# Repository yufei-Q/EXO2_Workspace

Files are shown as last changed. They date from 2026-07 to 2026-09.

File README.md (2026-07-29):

# EXO2 Workspace

本仓库统一管理外骨骼控制系统的 STM32 固件、ROS 1 Noetic 上位机和 ROS 2 Jazzy 上位机代码。所有电脑都使用同一个 `main` 分支并下载完整仓库。

## 目录结构

```text
EXO2_Workspace/
├── stm32/
│   ├── EXO2_DM_G474/       STM32G474 七电机正式工程
│   ├── EXO2_DM_MOTOR/      STM32F407 旧版四电机工程
│   └── motor_test/         STM32F407 电机测试工程
├── ubuntu/
│   ├── ros_noetic/         Ubuntu 20.04 + ROS 1 Noetic
│   └── ros_jazzy/          Ubuntu 24.04 + ROS 2 Jazzy
├── windows/                Windows USB CDC上位机工具
└── docs/
    └── archive/            历史测试说明
```

当前正式配套代码：

- STM32：[stm32/EXO2_DM_G474](stm32/EXO2_DM_G474)
- ROS 1：[ubuntu/ros_noetic/exo_bringup](ubuntu/ros_noetic/exo_bringup)
- ROS 2：[ubuntu/ros_jazzy/exo_bringup](ubuntu/ros_jazzy/exo_bringup)
- 通信协议：[stm32/EXO2_DM_G474/G474_MOTOR_PROTOCOL.md](stm32/EXO2_DM_G474/G474_MOTOR_PROTOCOL.md)

三套正式代码均对应7台电机：CAN ID 1～4为D4340P，CAN ID 5～7为D4310P；USB控制帧156字节，反馈帧114字节。7台电机共享一个全局控制模式，支持MIT模式和速度模式。

## 分支规则

仓库只长期维护 `main`。Windows、Ubuntu 20.04和Ubuntu 24.04电脑都直接在 `main` 上工作。

每次开始修改前：

```bash
git switch main
git pull --rebase origin main
```

修改和测试完成后：

```bash
git status
git diff
git add -A
git status
git commit -m '说明本次修改'
git push origin main
```

提交前必须检查 `git status`。不要提交Keil、catkin、colcon和Python生成文件。

更完整的协作规则见 [docs/REPOSITORY_WORKFLOW.md](docs/REPOSITORY_WORKFLOW.md)。

## STM32工程

正式工程文件：

```text
stm32/EXO2_DM_G474/EXO2_DM_G474.ioc
stm32/EXO2_DM_G474/MDK-ARM/EXO2_DM_G474.uvprojx
```

Keil编译输出不会进入Git。其他电脑第一次编译时，Keil会重新生成输出目录和HEX文件。

## ROS文档

- ROS 1安装和运行：[ubuntu/ros_noetic/exo_bringup/README.md](ubuntu/ros_noetic/exo_bringup/README.md)
- ROS 2安装和运行：[ubuntu/ros_jazzy/exo_bringup/README.md](ubuntu/ros_jazzy/exo_bringup/README.md)

ROS 1和ROS 2是两套独立代码，功能包名称统一为 `exo_bringup`，节点接口和USB协议保持一致；不要在两个目录之间复制构建产物。

Windows独立测试工具见 [windows/stm32_usb_motor_tool](windows/stm32_usb_motor_tool)。

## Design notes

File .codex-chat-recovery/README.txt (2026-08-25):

Codex local chat recovery backup

Created: 2026-08-12 11:30:53 Asia/Shanghai

Reason:
Older STM32 chat sessions were associated with E:\ZJU\stm32_project,
which no longer exists. The active workspace is now:
E:\ZJU\EXO\stm32\stm32_project

Backup files in the timestamped directory were created before changing
the old sessions' cwd association in the Codex state database.

No authentication files are included.

The timestamped backup directory is intentionally ignored by Git because
it contains private local conversation metadata.

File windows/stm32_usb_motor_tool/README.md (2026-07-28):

# Windows STM32 USB 电机测试工具

该工具通过 Windows 的 USB CDC 虚拟串口直接与 `EXO2_DM_G474` 通讯，不依赖 ROS。协议与 STM32 当前的 7 电机 USB 协议一致：控制帧 156 字节，反馈帧 114 字节，默认控制和反馈频率为 500 Hz。

## 安装

安装 Python 3，然后在 PowerShell 中进入本目录：

```powershell
py -m pip install -r requirements.txt
```

列出串口：

```powershell
py .\stm32_motor_console.py --list
```

启动程序（把 `COM3` 换成实际端口）：

```powershell
py .\stm32_motor_console.py --port COM3 --rate 500
```

串口的 `115200` 仅用于满足虚拟串口接口参数；USB CDC 的实际传输不由传统 UART 波特率决定。

## 安全测试顺序

开始前确保 ROS 节点、串口助手等程序已经关闭，同一时刻只能有一个程序打开该 COM 口。首次测试只连接1号电机，并确保可以随时切断48 V电源。

程序启动后默认持续发送“全部失能、全部目标为零”的安全帧。

先检查 STM32 USB feedback：

```text
motor> stats
motor> feedback
```

`RX` 应持续增加。电机未使能时，反馈值可能为零或保持上一次数据。

只使能1号电机，控制量仍保持全零：

```text
motor> enable 1
```

设置1号电机MIT目标，参数依次为位置、速度、Kp、Kd、前馈力矩：

```text
motor> set 1 0 0 0 0 0
```

建议先保持 `Kp=0`、`Kd=0`、`torque=0`，确认反馈正常后再从很小的增益和目标开始。

读取最新反馈：

```text
motor> feedback
```

失能1号电机：

```text
motor> disable 1
```

其他命令：

```text
clear 1       清除1号电机错误
zero 1        将1号电机当前位置设为零位
enable all    使能全部电机（首次测试不要使用）
disable all   失能全部电机
stats         查看USB收发及CRC计数
quit          失能全部电机并退出
```

退出程序时会连续发送5帧全部失能指令，然后关闭串口。

## 判断结果

- `TX` 增加、`RX` 增加：Windows 与 STM32 USB 双向通讯正常。
- `TX` 增加、`RX=0`：STM32 没有向电脑返回数据，或打开了错误的 COM 口。
- `CRC errors` 增加：上下位机协议或数据流存在不一致。
- feedback 持续收到但电机字段不变化：USB 正常，应检查 STM32 与电机的 FDCAN 接收。

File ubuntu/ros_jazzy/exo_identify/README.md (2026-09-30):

# exo_identify

七自由度外骨骼的 MuJoCo 动力学数据采集、Pinocchio 线性参数辨识、独立验证，以及
ROS 2 实机采集/重力补偿工具。默认模型是：

```text
urdf/exo.SLDASM/urdf/装配体.SLDASM.urdf
```

该模型包含 `joint1` 到 `joint7`、完整惯量和 SolidWorks STL 网格。旧的
`urdf/estimator_kinematics.urdf` 仅保留作历史参考，不再是默认辨识模型。

`urdf/exo.SLDASM/` 保留 SolidWorks 导出的完整 URDF 文件夹，包括网格、关节名
配置及原始 ROS 1 导出元数据。当前 ROS 2 程序直接读取其中的
`urdf/装配体.SLDASM.urdf` 和 `meshes/`；其余导出文件作为模型来源和兼容参考保留，
不会被当前 ROS 2 主流程主动调用。

### 单独检查 MuJoCo 模型方向

在确定安装坐标系前，仅使用 `scripts/mujoco_model.py` 检查模型，不运行数据采集
或辨识。该脚本的姿态、关节、重力和自由体选项只作用于本次生成的 MuJoCo 模型，
不会修改 URDF 或辨识配置。

直接运行脚本会读取统一配置、生成预览 MJCF，并打开交互式 MuJoCo Viewer。省略
`--base-rpy` 和 `--base-pos` 时，程序读取 `config/identification.json` 中
`simulation.base_orientation_rpy` 和 `simulation.base_position`：

```bash
cd ~/exo_ws/src/exo_identify
python3 scripts/mujoco_model.py
```

该命令还会打开关节角度控制面板。七个滑块使用角度制，右侧实时显示实际角度和
执行器力矩。`Angle control (actuators)` 默认关闭，此时电机力矩为零，各关节在
重力下自由运动；开启后使用配置文件中的 `position_kp`、`velocity_kd` 和
`torque_limits` 进行重力前馈加 PD 角度控制。`Hold current pose` 会把当前实际角度
设为目标并开启控制，`Reset` 恢复 `--joint-positions` 指定的初始姿态。MuJoCo Viewer
中的快捷键 `C`、`H`、`R` 分别对应切换控制、保持当前姿态和复位。

寻找机械角度限幅时，可慢速移动单个关节滑块，并观察实际角度、力矩和接触数量。
滑块默认范围为 `-180` 到 `180` 度，可按需要修改；例如：

```bash
python3 scripts/mujoco_model.py --angle-range-deg -120 120
```

若希望启动时立即保持初始设定角度，加入 `--control-on`。只需要原始 Viewer、不需要
角度控制面板时使用 `--no-gui`。

无图形桌面或只想做无窗口检查时使用 `--no-viewer`；需要保存 PNG 时才显式加入
`--preview`，默认写入 `results/seven_dof/model_visualization/exo_orientation.png`：

```bash
python3 scripts/mujoco_model.py \
  --joint-positions 0 0 0 0 0 0 0 \
  --show-frames --fixed-base --no-viewer --preview
```

测试候选方向时，可以直接用弧度覆盖配置，例如绕世界 Y 轴旋转 90 度：

```bash
python3 scripts/mujoco_model.py \
  --base-pos 0 0 0 \
  --base-rpy 0 1.5708 0 \
  --joint-positions 0 0 0 0 0 0 0 \
  --show-frames --fixed-base --no-viewer \
  --preview results/seven_dof/model_visualization/exo_orientation_y90.png
```

有图形桌面时也可以显式写 `--viewer` 查看交互窗口；两者不能同时使用：

```bash
python3 scripts/mujoco_model.py --show-frames --fixed-base --viewer
```

`--base-rpy` 使用弧度，顺序为世界坐标中的 XYZ roll/pitch/yaw；`--gravity`
是 MuJoCo 世界坐标中的重力向量，必须显式给出。坐标轴颜色为 X 红、Y 绿、Z 蓝；
黄色线段指向重力方向。基座默认固定在 MuJoCo 世界坐标中，`--fixed-base` 用于
显式确认该模式；此时只有各关节在重力下运动，外骨骼整体不会下落。若之后需要
整体自由下落，再使用 `--free-base --contacts` 或组合选项 `--drop`。自由基座模式
下，MuJoCo 窗口中可使用其标准鼠标扰动操作拖动自由体。无图形桌面时使用
`--preview` 生成静态 PNG；它不会模拟掉落。若省略
`--output`，预览 MJCF 默认写入 `results/seven_dof/model_visualization/`；脚本不再默认
生成 PNG，也不使用 `/tmp` 保存结果。

生成的 MJCF 是后续轨迹设计、数据采集、补偿验证和交互仿真共同使用的唯一模型。
每个 URDF 网格在其中分成两类：原 STL 只负责显示，显式关闭接触；由 URDF
`collision` 网格生成的凸包只负责碰撞，开启 MuJoCo 接触。碰撞体使用
`config/identification.json` 中的 `collision.minimum_clearance_m`（默认 `0.005 m`）
作为提前接触距离，并排除直接相连的父子刚体。当前实现不会向 URDF 或 MJCF 增加
关节限位，生成的七个关节仍为 `limited=false`；运动范围继续由激励轨迹的原有角度、
速度和加速度条件决定。

## 1. 安装与构建

系统需要 ROS 2 Jazzy、NumPy、SciPy、Pinocchio、Matplotlib 和 Pillow。
MuJoCo 单独安装：

```bash
python3 -m pip install -r ~/exo_ws/src/exo_identify/requirements-mujoco.txt

cd ~/exo_ws
source /opt/ros/jazzy/setup.bash
colcon build --symlink-install --packages-select exo_bringup exo_identify
source install/setup.bash
```

`~/exo_ws/src/exo_identify` 和 `~/exo_ws/src/exo_bringup` 是指向 Git 仓库的软连接；
因此只需修改一份源码，两端会保持一致。修改后仍需重新构建已安装的 ROS 包。

## 2. MuJoCo 完整动力学辨识与仿真部署

完整仿真流程由六个可独立执行的阶段组成：

```text
mujoco_model.py
    → design_excitation.py
    → collect_mujoco_dynamics.py
    → identify_parameters.py
    → export_gravity_formula.py
    → validate_mujoco_compensation.py
```

如果希望一次完成全部仿真阶段，可以运行调度脚本：

```bash
python3 scripts/mujoco_dynamics_pipeline.py all
```

调度脚本也支持逐阶段执行。每个阶段都会调用对应的独立脚本：

```bash
python3 scripts/mujoco_dynamics_pipeline.py model
python3 scripts/mujoco_dynamics_pipeline.py design
python3 scripts/mujoco_dynamics_pipeline.py collect
python3 scripts/mujoco_dynamics_pipeline.py identify
python3 scripts/mujoco_dynamics_pipeline.py export
python3 scripts/mujoco_dynamics_pipeline.py validate
```

因此 `pipeline` 只负责顺序和默认路径，不再把模型生成、采集、辨识和验证的实现
隐藏在同一个文件中。`all` 默认使用
`results/seven_dof/simulation_model/exo7_sim.xml`：模型不存在或缺少有效碰撞体时会
自动重新生成；显式提供 `--mjcf` 时不会静默覆盖该文件。需要主动重建时使用
`--regenerate-model`。轨迹报告会记录 MJCF 和碰撞凸包的 SHA-256 指纹；路径相同但
模型内容发生变化时，`all` 也会强制重新做轨迹碰撞筛选。

仿真采集会读取：

```text
results/seven_dof/excitation/excitation_id.csv
results/seven_dof/excitation/excitation_validation.csv
```

并使用同一个带碰撞的 MuJoCo 模型生成带 `_sim` 后缀的数据：

```text
results/seven_dof/simulation_model/exo7_sim.xml
results/seven_dof/simulation_data/dynamics_id_sim.csv
results/seven_dof/simulation_data/dynamics_validation_sim.csv
results/seven_dof/dynamics_identification/identified_parameters_sim.npz
results/seven_dof/dynamics_identification/prediction_id_sim.csv
results/seven_dof/dynamics_identification/prediction_validation_sim.csv
results/seven_dof/dynamics_identification/identification_report_sim.json
results/seven_dof/dynamics_identification/gravity_formula_sim.json
results/seven_dof/compensation_validation/compensation_validation_sim.csv
results/seven_dof/compensation_validation/compensation_report_sim.json
```

`dynamics_id_sim.csv` 中的力矩来自 MuJoCo 前向动力学中的执行器反馈：位置/速度
指令先经过虚拟伺服器，MuJoCo 用 `mj_step` 积分，然后读取实际的 `q`、`dq`、
`qacc` 和 `qfrc_actuator`。模型包含配置的关节阻尼、等效转子惯量和关节摩擦损失，
并默认加入小幅控制扰动、外部力矩扰动和测量噪声；辨识程序强制打开摩擦项。
`identified_parameters_sim.npz`
同时包含刚体参数和 `Fv/Fc` 摩擦参数，可作为补偿节点的仿真模型。

当前虚拟伺服器参数集中写在 `config/identification.json`：`Kp=20`、`Kd=1`、
力矩限幅为 `8 N·m`。采集器不使用模型前馈力矩；因此记录的是控制器真正施加后，
MuJoCo 前向积分产生的执行器反馈。需要改变扰动或传感器噪声时，只修改同一文件
`simulation.noise` 下的六组标准差，或用 `--torque-noise-std` 临时覆盖力矩测量噪声。

`validate` 阶段（`all` 会自动执行）使用独立激励验证轨迹，分别比较 MuJoCo 的重力、
被动摩擦和辨识模型输出，并生成 `compensation_validation_sim.csv` 与
`compensation_report_sim.json`。这是部署前的仿真闭环检查，不等同于实机安全测试；
其中摩擦模型采用平滑 `tanh`，在库仑摩擦速度过零处出现的误差会单独记录。

确认正确方向后，把角度写入 `config/identification.json` 的
`simulation.base_orientation_rpy`。当前方向配置为：

```json
"simulation": {
  "base_position": [0.0, 0.0, 0.2],
  "base_orientation_rpy": [1.5708, 0.0, 0.0]
}
```

顶层的 `gravity: [0.0, 0.0, -9.81]` 仍表示 MuJoCo 世界坐标中的重力，不要为了补偿
基座旋转而手工改成其他方向。`mujoco_model.py` 在生成 MJCF 时将基座旋转应用到 MuJoCo 模型；Pinocchio
辨识模型会自动把同一个世界重力转换到 URDF 基座坐标系，因此两边使用的是同一个
物理方向。`base_position` 同理用于设置基座在世界坐标中的位置。

修改方向、碰撞间隙或模型几何后，应重新生成 MJCF 和轨迹，再完成采集、辨识和
验证：

```bash
python3 scripts/mujoco_dynamics_pipeline.py all \
  --regenerate-model --regenerate-trajectory
```

之后直接运行 `mujoco_model.py` 会从该配置读取相同姿态，不需要手工编辑 XML。

`simulation_*`、`compensation_validation/` 和所有 `_sim` 文件只代表仿真数据。实物采集数据使用
`hardware_experiments/` 或用户指定的实物结果目录，不应覆盖仿真文件。
模型可视化目录只在显式使用 `mujoco_model.py --preview` 时生成 PNG；直接运行脚本只打开
Viewer 并生成 MJCF，不会自动保存 PNG。

## 3. 阶段一：生成七自由度动态激励轨迹

完整动力学/摩擦辨识继续使用原有线性回归流程，现已按 `model.nv` 支持七关节：

```bash
python3 scripts/design_excitation.py \
  --mjcf results/seven_dof/simulation_model/exo7_sim.xml \
  --output-dir results/seven_dof/excitation
```

输出 `excitation_id.csv`、`excitation_validation.csv`、
`base_parameter_set.npz` 和 `excitation_report.json`。默认轨迹范围、速度和加速度在
`config/identification.json` 中统一配置为七个元素。`target_position_center` 表示整条
轨迹范围的中心，不保证 CSV 的第一帧就是零位；当前代码只把起点选择为尽量接近整体
中心的已有轨迹采样点。

轨迹候选仍先通过原有角度、速度和加速度条件，不改变原来的信息矩阵评分方式。
随后程序在 `sample_time=0.02 s` 的候选点上用 MuJoCo 做碰撞粗筛，对剩余候选按原
评分排序，再以 MJCF 的 `0.002 s` 步长同时密集检查辨识轨迹和独立验证轨迹。只有
两条轨迹都满足 `5 mm` 间隙的最高分候选才会写入 CSV。若当前 `5.2 rad` 峰峰值等
条件下全部候选均碰撞，脚本会明确失败且不覆盖已有轨迹；它不会自动缩小运动范围或
关闭碰撞检查。此时应根据碰撞报告决定增加候选数量、改变轨迹参数化，或经过工程评估
后显式调整轨迹范围。

## 4. 阶段二：采集 MuJoCo 仿真辨识数据

仿真数据采集现在有单独入口，不需要通过总 pipeline 才能执行：
具体的前向动力学、虚拟伺服、扰动注入和传感器读取都实现在
`scripts/collect_mujoco_dynamics.py`；采集器只加载已有的 MJCF，不会再次从 URDF
生成模型。`scripts/mujoco_dynamics_pipeline.py` 只负责按顺序调用各阶段。

先使用 `mujoco_model.py` 生成本次配置对应的模型：

```bash
python3 scripts/mujoco_model.py \
  --no-viewer \
  --output results/seven_dof/simulation_model/exo7_sim.xml
```

然后加载该模型进行采集：

```bash
python3 scripts/collect_mujoco_dynamics.py \
  --mjcf results/seven_dof/simulation_model/exo7_sim.xml
```

如果需要在数据计算的同时观察 MuJoCo 当前姿态，可以显式打开实时 Viewer：

```bash
python3 scripts/collect_mujoco_dynamics.py \
  --mjcf results/seven_dof/simulation_model/exo7_sim.xml \
  --viewer
```

窗口显示的是采集循环正在计算的当前轨迹样本，不是采集结束后再读取 CSV 的回放。
默认按轨迹真实时间运行；例如 `--viewer-speed 2` 可以用两倍速度观察。无图形界面时
不要加 `--viewer`。一键流程也支持相同选项：

```bash
python3 scripts/mujoco_dynamics_pipeline.py all --viewer
```

该脚本只负责将激励轨迹输入 MuJoCo，运行前向动力学并记录执行器反馈 `tau`。
它不进行参数辨识、公式导出或补偿验证。输出为：

```text
results/seven_dof/simulation_data/dynamics_id_sim.csv
results/seven_dof/simulation_data/dynamics_validation_sim.csv
results/seven_dof/simulation_data/simulation_metadata_sim.json
```

采集过程中，接触求解始终开启，并在每个 MuJoCo `0.002 s` 积分步后检查配置的最小
间隙。任一时刻违反间隙都会终止采集；辨识和验证两条轨迹未全部通过前，两份 CSV
均不会被替换。这样既保留实际接触物理，也防止把碰撞状态混入辨识数据。

## 5. 阶段三和四：参数辨识与重力公式导出

如果已有七关节动态数据（仿真或实物），可运行通用辨识程序。仿真数据建议保留
`_sim` 后缀：

```bash
python3 scripts/identify_parameters.py \
  --id-data results/seven_dof/simulation_data/dynamics_id_sim.csv \
  --validation-data results/seven_dof/simulation_data/dynamics_validation_sim.csv \
  --base-set results/seven_dof/excitation/base_parameter_set.npz \
  --output-dir results/seven_dof/dynamics_identification \
  --friction on \
  --suffix sim
```

若下游系统只能读取 JSON，可把辨识参数精确展开为七维三角公式：

```bash
python3 scripts/export_gravity_formula.py \
  --parameters results/seven_dof/dynamics_identification/identified_parameters_sim.npz \
  --base-set results/seven_dof/excitation/base_parameter_set.npz \
  --output results/seven_dof/dynamics_identification/gravity_formula_sim.json
```

七维公式会比 `.npz` 大；ROS 补偿节点优先直接读取 `.npz`，这样没有公式近似误差。

独立执行仿真补偿验证：

```bash
python3 scripts/validate_mujoco_compensation.py
```

该脚本先确认 MJCF 的碰撞体和间隙配置有效，并再次检查验证轨迹无碰撞，再比较
MuJoCo 参考重力/摩擦项与辨识模型输出；它不会修改辨识参数。

## 6. 实机七关节采集

实机映射统一位于 `config/hardware_mapping.yaml`，默认是七路一一映射：

```yaml
motor_indices: [0, 1, 2, 3, 4, 5, 6]
joint_directions: [1.0, 1.0, 1.0, 1.0, 1.0, 1.0, 1.0]
```

`experiment.yaml` 和 `gravity_compensation.yaml` 只包含各自节点的功能参数；
不要在这两个文件中重复维护电机映射、方向、零位或传动比例。两个 launch
文件默认都会读取 `config/hardware_mapping.yaml`，也可以通过
`hardware_mapping_file:=...` 临时指定另一份标定文件。

实物采集必须逐步执行，不放入仿真一键 pipeline。轨迹实验 launch 已内置默认轨迹
`results/seven_dof/excitation/excitation_id.csv`，因此可以直接启动：

```bash
ros2 launch exo_identify trajectory_experiment.launch.py
```

仍可通过 `trajectory_file:=...` 指定其他轨迹。

这些只是仿真一致的占位值。连接实机前必须校准每个电机的零点、方向、减速比、
力矩比例及机械限位，不可直接沿用默认配置。

`trajectory_experiment.launch.py` 默认启用底层轨迹准备互锁：`dm_motor_usb` 只有在
轨迹节点完成 `prepare` 并持续收到准备心跳时才接受电机使能；忘记 `prepare`、轨迹
节点退出或反馈超时都会撤销使能资格。单独启动 `dm_motor_usb.launch.py` 时该互锁
默认关闭，以保留手动电机调试行为；这不应被用于人体佩戴测试。

```bash
ros2 launch exo_identify trajectory_experiment.launch.py \
  trajectory_file:=$PWD/results/seven_dof/excitation/excitation_id.csv

ros2 service call /exo_identify/prepare std_srvs/srv/Trigger '{}'
ros2 topic pub --once /dm_motor_usb/enable std_msgs/msg/Bool '{data: true}'
ros2 service call /exo_identify/start std_srvs/srv/Trigger '{}'
```

采集节点会保存七路原始反馈和处理后的 `measured_id.csv`。正常停止使用
平滑减速；需要软件立即禁用时调用：

```bash
ros2 service call /exo_identify/emergency_stop std_srvs/srv/Trigger '{}'
```

反馈超时、位置/速度越界也会自动立即禁用。该软件服务不能替代独立的硬件急停。
已有的 2 自由度生成结果保留在 `results/two_dof/`，当前七自由度流程默认写入
`results/seven_dof/`，两者不会混用。

## 7. 实机/仿真重力与摩擦补偿部署

补偿节点可直接加载 `.npz` 线性动力学模型。模型中的刚体参数用于重力项，
辨识出的 `Fv/Fc` 参数用于摩擦项：

默认模型是仿真辨识得到的
`results/seven_dof/dynamics_identification/identified_parameters_sim.npz`，因此可以直接启动：

```bash
ros2 launch exo_identify gravity_compensation.launch.py
```

```bash
ros2 launch exo_identify gravity_compensation.launch.py \
  formula_file:=$PWD/results/seven_dof/dynamics_identification/identified_parameters_sim.npz
```

也兼容 `gravity_formula_sim.json`（该 JSON 主要用于重力公式展示）。部署实物时，
应将 `formula_file` 指向经过实物数据重新辨识并验证的模型，不要直接把 `_sim` 参数
当作实物最终标定结果。安全比例、七关节力矩限幅和映射位于
`config/gravity_compensation.yaml`。准备、渐增和停止：

```bash
ros2 service call /exo_identify/gravity/prepare std_srvs/srv/Trigger '{}'
ros2 topic pub --once /dm_motor_usb/enable std_msgs/msg/Bool '{data: true}'
ros2 service call /exo_identify/gravity/start std_srvs/srv/Trigger '{}'
ros2 service call /exo_identify/gravity/stop std_srvs/srv/Trigger '{}'
```

首次实机测试必须脱离人体、可靠支撑、降低补偿比例并准备硬件急停。仿真辨识只能
证明算法与 URDF/MuJoCo 一致，不能替代真实电机方向、传动比例和机械安全校准。

## 8. 交互式 MuJoCo 重力/摩擦补偿仿真

为了在不连接电机的情况下观察补偿效果，提供了独立的实时仿真入口。它只加载已经
由 `mujoco_model.py` 生成的 MJCF，不会重新生成模型：

```bash
python3 scripts/mujoco_compensation_sim.py
```

该入口同样要求 MJCF 包含已启用的碰撞体。Viewer 中 MuJoCo 会正常求解接触，日志和
状态栏分别给出进入安全间隙的接触数与实际穿透接触数。软接触求解不能提供数学意义上
的绝对零穿透保证，因此部署策略仍是先用轨迹的 `5 mm` 间隙把碰撞排除在正常运行域
之外，再由 MuJoCo 接触处理意外扰动。

窗口由两部分组成：MuJoCo Viewer 负责显示模型和鼠标扰动，旁边的控制面板负责实时
开关和调参。控制面板可以修改重力/摩擦补偿开关、各自比例、关节角度噪声、角速度
噪声、角加速度噪声、速度制动阻尼、控制器力矩噪声和随机外部关节力矩。Viewer 中
按住鼠标拖动一个刚体时，MuJoCo 会把扰动力转换到关节广义力；松开鼠标后该力消失。快捷键 `G`、`F`、
`N` 分别切换重力、摩擦和噪声，空格暂停，`R` 回到初始姿态。

交互仿真默认开启重力补偿，默认关闭主动摩擦补偿和速度制动。MuJoCo 模型的被动
关节参数为 `damping=0.4 N.m/(rad/s)`、`frictionloss=0.15 N.m`，因此默认停止过程
来自仿真关节本身的被动耗散。速度制动接口仍保留，用于和主动速度反馈控制做对比。
这些数值是当前仿真的统一占位值，不代表实物测量结果；获得真实摩擦数据后应重新
标定它们并重新完成仿真采集、辨识和验证。

仿真的数据流是：

```text
MuJoCo真实 q/dq/qacc
    ├─ 加测量噪声 → 补偿模型输入(q,dq)
    └─ qacc 加噪 → 记录的加速度测量
补偿模型(q,dq) + 速度制动 + 控制器力矩噪声 → data.ctrl → MuJoCo mj_step
鼠标扰动/随机外力 ────────────────────────┘
```

`qacc` 噪声不会改变当前重力/摩擦公式，因为这两个补偿项分别只依赖 `q` 和 `dq`；
速度制动是额外的 `tau_brake=-K_d*dq` 项，默认仅在重力补偿开启时生效。它用于
消除“先关闭重力补偿使机构获得速度，再重新开启重力补偿”时的剩余动能；它不是对
辨识得到的库仑/黏性摩擦参数的修改。若只想观察原始被动摩擦效果，可在控制面板中
关闭速度制动并把摩擦补偿关闭。带噪 `qacc` 仍会写入日志，便于以后接入完整的
惯性/科氏力控制器时复用。MuJoCo 的真实状态
不会被传感器噪声改写，日志同时保留了真实量、带噪测量量、补偿分量和实际执行器力矩。
默认输出为：

```text
results/seven_dof/compensation_simulation/live_compensation.csv
```

没有图形桌面时可做短时无窗口检查（必须给出有限时长）：

```bash
python3 scripts/mujoco_compensation_sim.py \
  --no-viewer --no-gui --duration 2
```

也可以通过 ROS 2 launch 启动同一个程序：

```bash
ros2 launch exo_identify mujoco_compensation_sim.launch.py
```

这条仿真入口不会发布 `/dm_motor_usb/enable` 或真实电机命令，因此不会连接或使能实机。

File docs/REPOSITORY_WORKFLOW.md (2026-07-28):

# 仓库使用规则

## 总体原则

- 一个GitHub仓库：`EXO2_Workspace`。
- 一个长期分支：`main`。
- 所有电脑克隆完整仓库。
- Windows、ROS 1和ROS 2代码都提交到同一个 `main`。
- Git只保存源码、工程配置和说明文档，不保存可重新生成的编译产物。

## 各电脑主要修改范围

| 环境 | 主要目录 |
|---|---|
| Windows + STM32CubeMX/Keil | `stm32/` |
| Ubuntu 20.04 + ROS 1 Noetic | `ubuntu/ros_noetic/` |
| Ubuntu 24.04 + ROS 2 Jazzy | `ubuntu/ros_jazzy/` |

不同电脑可以查看和修改全部代码，但一次提交应只包含本次实际需要的变化。

## 开始工作

```bash
git switch main
git pull --rebase origin main
git status
```

只有在工作区干净或确认现有修改属于自己时再开始工作。

## 提交代码

```bash
git status
git diff
git add -A
git status
git commit -m 'feat(stm32): describe the change'
git push origin main
```

推荐提交前缀：

- `feat(stm32):` STM32新功能。
- `fix(stm32):` STM32问题修复。
- `feat(ros1):` ROS 1功能。
- `feat(ros2):` ROS 2功能。
- `fix(protocol):` 三端通信协议修复。
- `docs:` 文档修改。
- `chore:` 仓库结构或工具配置。

## 多台电脑同步

一台电脑推送后，其他电脑继续修改前先执行：

```bash
git pull --rebase origin main
```

如果本地已经有未提交修改，不要直接强制拉取。先提交修改，或者确认内容后暂存到stash，再进行同步。

## 通信协议同步要求

修改USB帧格式、电机数量、量程或标志位时，必须同时检查：

1. `stm32/EXO2_DM_G474/Core/Src/usb_motor_comm.c`
2. `stm32/EXO2_DM_G474/Core/Src/dm_motor.c`
3. `ubuntu/ros_noetic/exo_bringup/scripts/node.py`
4. `ubuntu/ros_jazzy/exo_bringup/scripts/protocol.py`
5. `stm32/EXO2_DM_G474/G474_MOTOR_PROTOCOL.md`

不能只修改其中一端后直接连接电机测试。

## 不应提交的内容

- Keil的AXF、HEX、OBJ、MAP、日志和个人界面配置。
- ROS 1的 `build/`、`devel/`。
- ROS 2的 `build/`、`install/`、`log/`。
- Python的 `__pycache__/` 和 `.pyc`。
- 编辑器、操作系统和临时文件。

这些内容由根目录 `.gitignore` 自动排除。

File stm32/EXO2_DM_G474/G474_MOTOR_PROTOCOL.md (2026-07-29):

# STM32G474 七电机通信说明

## 系统配置

- MCU：STM32G474VET6，系统时钟 168 MHz。
- USB：USB Device CDC FS，STM32 与 ROS 上位机传输控制指令和反馈。
- FDCAN1：PD0 为 RX，PD1 为 TX，必须连接支持 CAN FD 的外部收发器。
- FDCAN 仲裁段：1 Mbps。
- FDCAN 数据段：4 Mbps，启用 BRS。
- 电机 1～4：D4340P。
- 电机 5～7：D4310P。
- 电机主机 ID：0。
- 控制模式：7 台电机共享同一个全局模式，支持 MIT 模式和速度模式。
- TIM6 中断频率：3500 Hz；每次只发送一台电机，7 台电机各 500 Hz。
- USB 指令超过 100 ms 未更新时，STM32 停止周期控制帧并依次发送失能指令。

所有电机必须设置 CAN FD 波特率代码 8、对应 ID 1～7，并将 Master ID 设置为 0。STM32在首次收到USB命令以及模式发生变化时，会统一写入7台电机的控制模式寄存器。同一总线两端各放置一个 120 Ω 终端电阻，不要在每台电机处都增加终端电阻。

## USB 帧格式

整数和 float 均按小端发送，float 为 IEEE 754 单精度。CRC 使用 CRC-16/CCITT-FALSE：初值 0xFFFF，多项式 0x1021，不反转，无最终异或。CRC 计算范围从帧类型开始，到负载最后一个字节结束，不包含帧头与 CRC 字段。

### 通用帧头

| 偏移 | 长度 | 内容 |
|---:|---:|---|
| 0 | 1 | 0xAA |
| 1 | 1 | 0x55 |
| 2 | 1 | 类型：控制 0x01，反馈 0x81 |
| 3 | 2 | 负载长度 uint16 |
| 5 | 2 | 序号 uint16 |
| 7 | N | 负载 |
| 7+N | 2 | CRC16 |

### ROS 到 STM32 控制帧

总长度为 156 字节，负载长度为 147 字节。负载依次放置电机 1～7，每台占 21 字节：

| 电机内偏移 | 长度 | 内容 |
|---:|---:|---|
| 0 | 1 | flags |
| 1 | 4 | position，rad |
| 5 | 4 | velocity，rad/s |
| 9 | 4 | kp |
| 13 | 4 | kd |
| 17 | 4 | torque，N·m |

flags 位定义：

- bit0：1 为使能，0 为失能。
- bit1：清除错误。
- bit2：设置当前位置为零位。
- bit4：0 为 MIT 模式，1 为速度模式。7台电机记录中的该位必须相同。

清错和设零属于动作命令。上位机应只置位一帧，随后清零对应位，避免重复执行。

### STM32 到 ROS 反馈帧

总长度为 114 字节，负载长度为 105 字节。负载依次放置电机 1～7，每台占 15 字节：

| 电机内偏移 | 长度 | 内容 |
|---:|---:|---|
| 0 | 1 | status |
| 1 | 4 | position，rad |
| 5 | 4 | velocity，rad/s |
| 9 | 4 | torque，N·m |
| 13 | 1 | MOS 温度，℃ |
| 14 | 1 | 转子温度，℃ |

反馈帧目标发送频率为 500 Hz。USB CDC 是字节流，一帧可能被拆成多个 USB 包；ROS 程序必须使用缓存按帧头和负载长度拼帧，不能假设一次 read 就得到完整帧。

## 控制模式切换

STM32使用一个全局控制模式。模式变化时执行以下过程：

1. 暂停7台电机的周期控制帧。
2. 依次发送失能指令。
3. 依次写入每台电机的`CTRL_MODE`寄存器`0x0A`。
4. 等待10 ms后更新全局模式并恢复调度。
5. 只有上位机仍请求使能时才会重新使能；ROS节点切换模式时会主动撤销使能并清零目标。

控制模式寄存器值：MIT模式为`1`，速度模式为`3`。模式写入只在当前上电周期生效，不执行Flash存储。

MIT模式控制帧沿用原格式：CAN ID为电机ID，DLC为8。速度模式控制帧为：

| 项目 | 内容 |
|---|---|
| CAN ID | `0x200 + motor_id` |
| DLC | 4 |
| D0～D3 | 目标速度`float`，单位rad/s，小端序 |

两种控制模式使用相同的电机反馈帧和USB反馈帧。

## MIT 量程核对

当前代码中的换算量程位于 `Core/Src/dm_motor.c`：

| 型号 | P_MAX | V_MAX | T_MAX |
|---|---:|---:|---:|
| D4340P | 12.5 | 20.0 | 28.0 |
| D4310P | 12.5 | 50.0 | 10.0 |

这些值必须与每台电机内部的 PMAX、VMAX、TMAX 参数完全一致，否则物理量换算会错误。首次连接实物前，应使用达妙上位机逐台读取并确认；若实际值不同，只修改 `dm_motor.c` 顶部对应的三个宏。

## 首次测试顺序

1. 先不安装外骨骼负载，并确保急停和 48 V 电源可随时断开。
2. 只连接一台电机，确认其 ID、MIT 模式、Master ID 和 CAN FD 波特率。
3. 上位机先发送 flags 为 0、kp/kd/torque 为 0 的控制帧，验证 USB 收发和反馈解析。
4. 给该电机置一次清错位，再发送使能位；保持 position 为当前反馈位置，kp、kd 从较小值开始。
5. 单台测试正常后再逐台接入，最后连接 7 台并检查每台反馈频率与总线错误计数。

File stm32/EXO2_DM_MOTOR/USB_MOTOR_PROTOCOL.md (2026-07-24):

# STM32–ROS USB CDC protocol

All multibyte values use little-endian byte order. Floating-point values are
IEEE-754 single precision. Each frame has this layout:

| Offset | Size | Field |
|---:|---:|---|
| 0 | 2 | Header `AA 55` |
| 2 | 1 | Frame type |
| 3 | 2 | Payload length |
| 5 | 2 | Sequence |
| 7 | N | Payload |
| 7+N | 2 | CRC16-CCITT |

CRC uses initial value `0xFFFF` and polynomial `0x1021`. It covers bytes from
frame type through the end of payload; the header and CRC itself are excluded.

## PC to STM32: type `0x01`

The payload contains four 21-byte motor records, ordered by CAN ID 1–4:

| Offset in record | Size | Field |
|---:|---:|---|
| 0 | 1 | Flags |
| 1 | 4 | Desired position, rad |
| 5 | 4 | Desired velocity, rad/s |
| 9 | 4 | MIT Kp |
| 13 | 4 | MIT Kd |
| 17 | 4 | Feedforward torque, N·m |

Flags are: bit 0 enable, bit 1 clear error, and bit 2 save current position as
zero. Clear-error and set-zero are one-shot operations.

## STM32 to PC: type `0x81`

The payload contains four 15-byte feedback records, ordered by CAN ID 1–4:

| Offset in record | Size | Field |
|---:|---:|---|
| 0 | 1 | Motor status |
| 1 | 4 | Position, rad |
| 5 | 4 | Velocity, rad/s |
| 9 | 4 | Torque, N·m |
| 13 | 1 | MOS temperature, °C |
| 14 | 1 | Rotor temperature, °C |

## ROS Noetic node

Install the serial dependency:

```bash
sudo apt install python3-serial
```

Copy or link `ros_noetic/d4340p_usb_bridge` into the `src` directory of a
catkin workspace, then build and run:

```bash
cd ~/catkin_ws
catkin_make
source devel/setup.bash
chmod +x src/d4340p_usb_bridge/scripts/d4340p_usb_node.py
rosrun d4340p_usb_bridge d4340p_usb_node.py _port:=/dev/ttyACM0
```

If no valid command frame is received for 100 ms, the STM32 disables every
enabled D4340P motor.

Topics and services are private to the node namespace:

- `command` (`sensor_msgs/JointState`): four positions, velocities and efforts.
- `enable` (`std_msgs/Bool`): enables or disables all four motors.
- `feedback` (`sensor_msgs/JointState`): measured motor state.
- `status` (`std_msgs/UInt8MultiArray`): four motor status codes.
- `temperature` (`std_msgs/Float32MultiArray`): MOS/rotor pairs.
- `clear_error` (`std_srvs/Trigger`).
- `set_zero` (`std_srvs/Trigger`).

Set MIT gains with `~kp` and `~kd`, each either one scalar or a four-value list.
The default gain is zero, so enabling alone does not create position stiffness.

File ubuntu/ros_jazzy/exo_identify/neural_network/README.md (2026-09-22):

# 七自由度神经网络动力学辨识

该目录提供纯 NumPy MLP，用七关节实验数据学习关节总力矩模型。输入按 CSV 自动推断
关节数；当前七自由度特征为：

```text
[sin(q1),cos(q1),...,sin(q7),cos(q7),dq1,...,dq7,ddq1,...,ddq7]
                                      -> [tau1,...,tau7]
```

训练和验证数据必须使用主 README 中的标准七关节 CSV 格式，且必须是不同采集记录：

脚本默认使用完整动力学仿真生成的
`results/seven_dof/simulation_data/dynamics_id_sim.csv` 和
`results/seven_dof/simulation_data/dynamics_validation_sim.csv`，因此可以直接运行：

```bash
python3 neural_network/train_neural_dynamics.py
```

```bash
ros2 run exo_identify train_neural_dynamics.py \
  --id-data run_id_1/measured_id.csv run_id_2/measured_id.csv \
  --validation-data run_validation/measured_id.csv \
  --output-dir results/seven_dof/neural_identification
```

离线复核：

```bash
ros2 run exo_identify predict_neural_dynamics.py \
  --model results/seven_dof/neural_identification/neural_dynamics_model.npz \
  --data run_validation/measured_id.csv \
  --output results/seven_dof/neural_identification/prediction_check.csv \
  --report results/seven_dof/neural_identification/prediction_check.json
```

Python 调用：

```python
from neural_dynamics_model import NeuralDynamicsModel

model = NeuralDynamicsModel.load('neural_dynamics_model.npz')
tau = model.predict(q=q7, dq=dq7, ddq=ddq7)
```

`training_config.json` 中两个部署阈值数组必须各包含七个元素。只有独立验证报告中
`deployment_recommended` 为 `true`，并且完成硬件方向、比例、限幅、斜坡、反馈超时
和训练域保护后，才可以考虑实机前馈。神经网络不是本项目默认的重力补偿模型；
默认路径是可解释的 Pinocchio 线性重力回归。

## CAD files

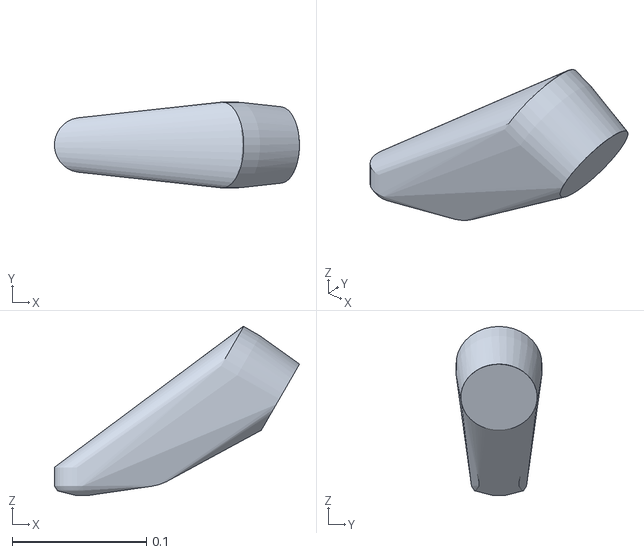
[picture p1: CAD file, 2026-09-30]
ubuntu/ros_jazzy/exo_identify/results/seven_dof/model_visualization/exo7_preview_sim_assets/link5_1_collision_hull.stl
0.183 x 0.0639 x 0.126

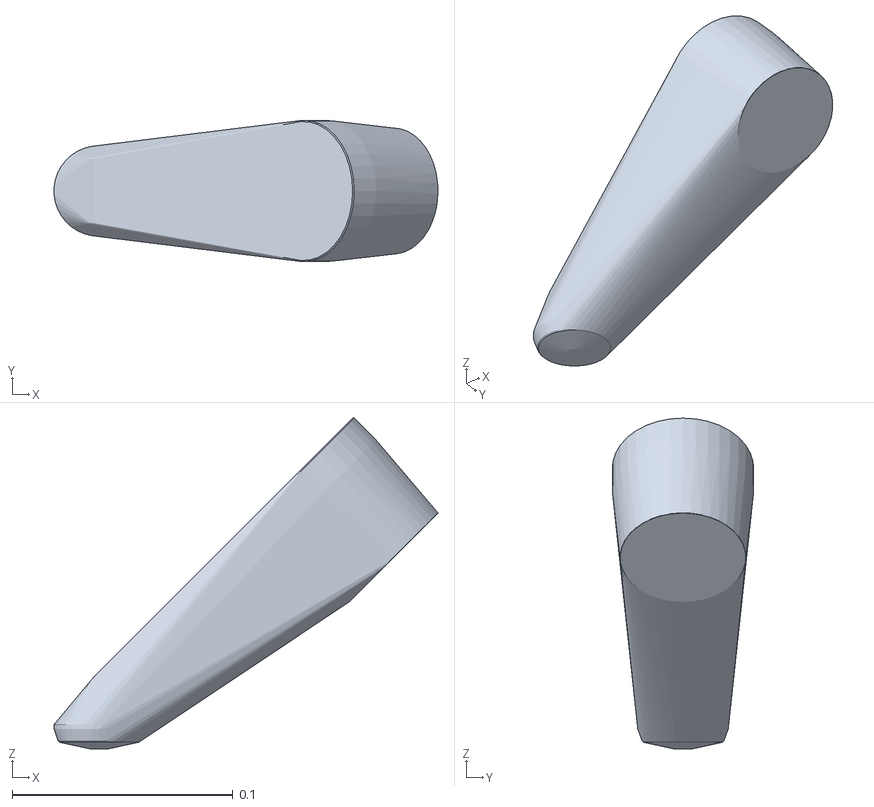
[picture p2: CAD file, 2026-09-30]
ubuntu/ros_jazzy/exo_identify/results/seven_dof/simulation_model/exo7_sim_assets/link2_1_collision_hull.stl
0.174 x 0.0639 x 0.15

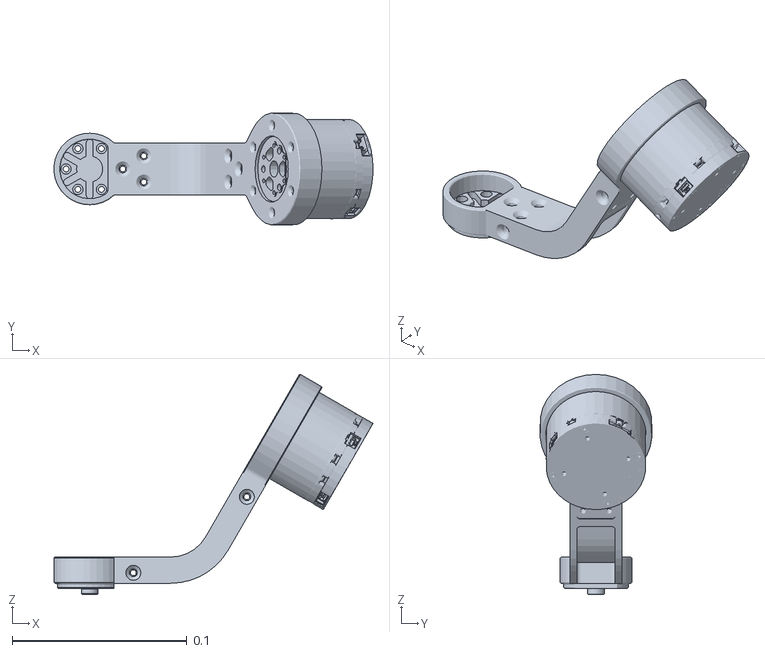
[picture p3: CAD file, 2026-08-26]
ubuntu/ros_jazzy/exo_identify/urdf/exo.SLDASM/meshes/link5.STL
0.183 x 0.0639 x 0.126

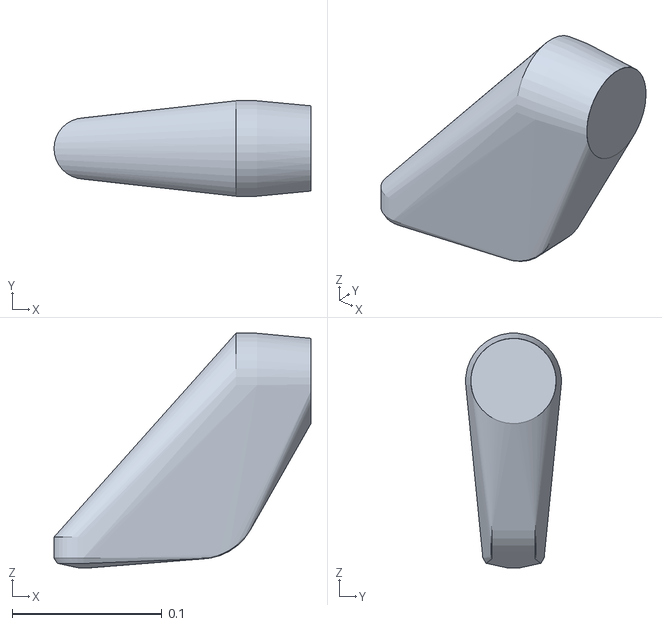
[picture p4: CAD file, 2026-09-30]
ubuntu/ros_jazzy/exo_identify/results/seven_dof/model_visualization/exo7_preview_sim_assets/link6_1_collision_hull.stl
0.172 x 0.0638 x 0.157

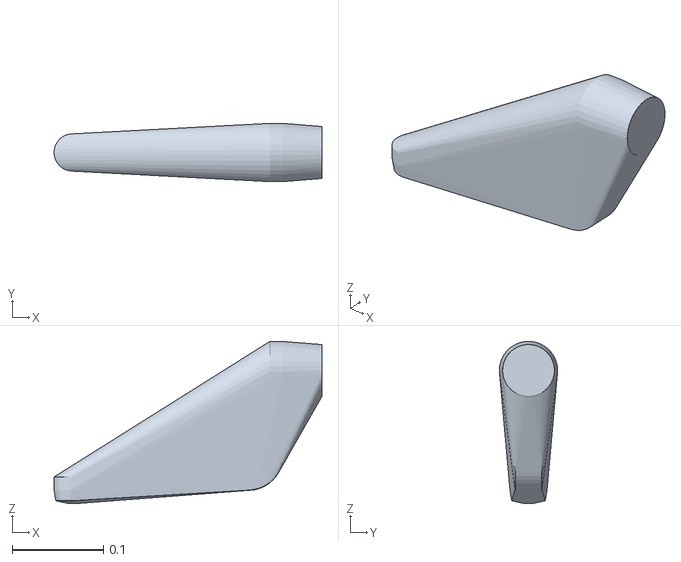
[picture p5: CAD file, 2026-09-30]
ubuntu/ros_jazzy/exo_identify/results/seven_dof/simulation_model/exo7_sim_assets/link1_1_collision_hull.stl
0.294 x 0.064 x 0.178

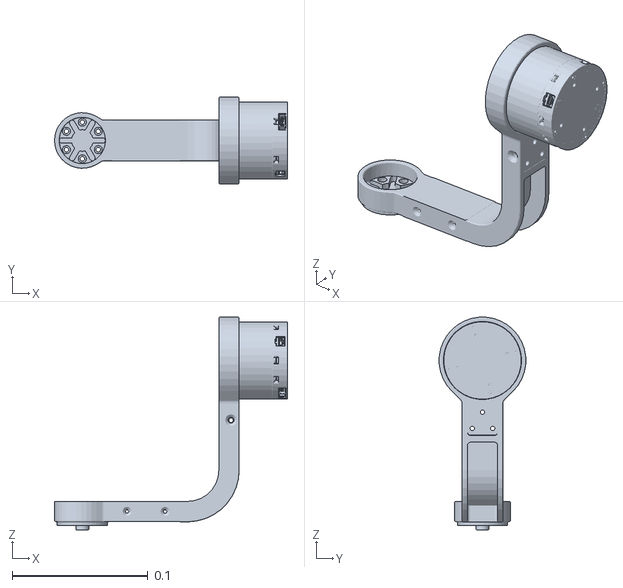
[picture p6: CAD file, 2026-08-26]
ubuntu/ros_jazzy/exo_identify/urdf/exo.SLDASM/meshes/link6.STL
0.172 x 0.0638 x 0.157

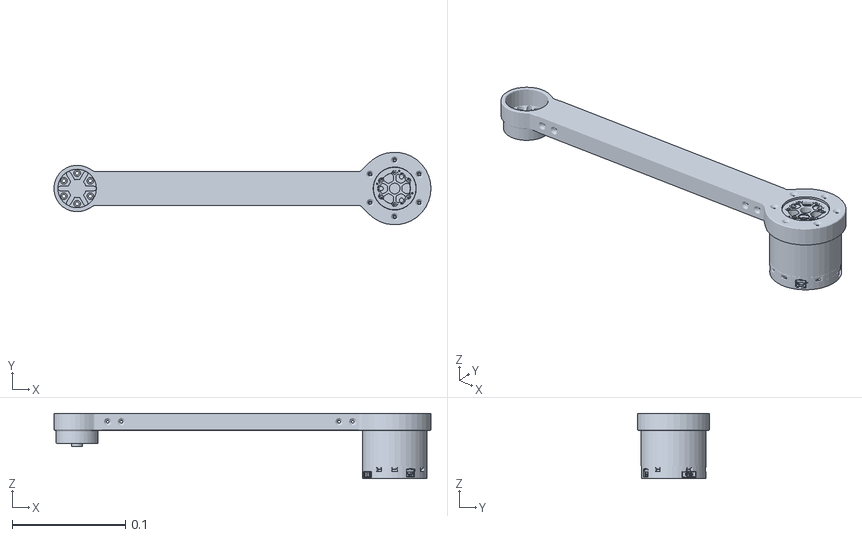
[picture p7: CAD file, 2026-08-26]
ubuntu/ros_jazzy/exo_identify/urdf/exo.SLDASM/meshes/link3.STL
0.332 x 0.0639 x 0.0578

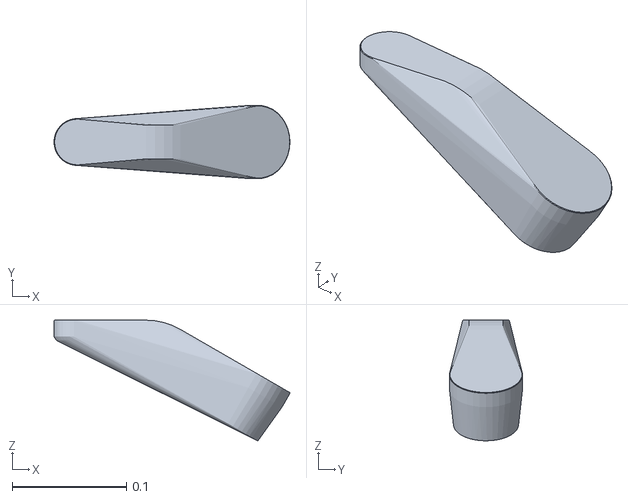
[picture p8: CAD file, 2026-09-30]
ubuntu/ros_jazzy/exo_identify/results/seven_dof/model_visualization/exo7_preview_sim_assets/link4_1_collision_hull.stl
0.206 x 0.0639 x 0.105

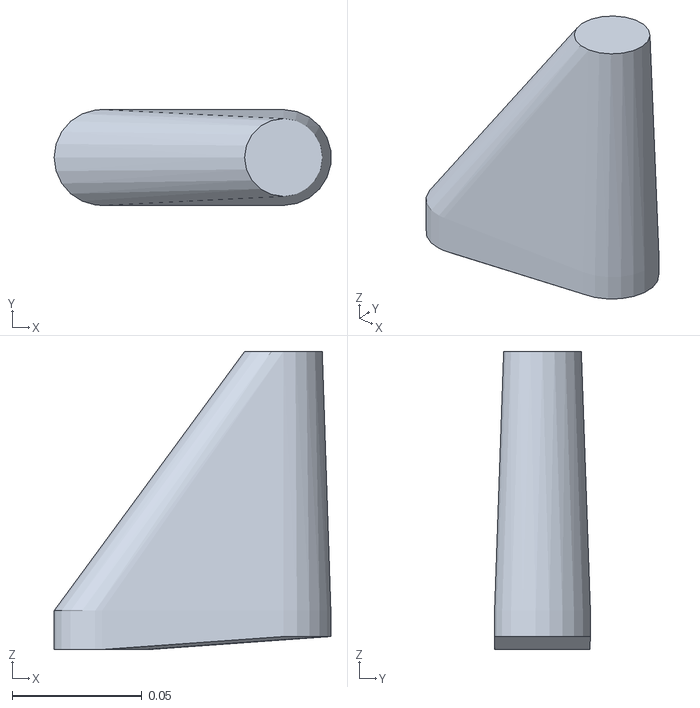
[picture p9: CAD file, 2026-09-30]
ubuntu/ros_jazzy/exo_identify/results/seven_dof/simulation_model/exo7_sim_assets/link7_1_collision_hull.stl
0.107 x 0.037 x 0.115

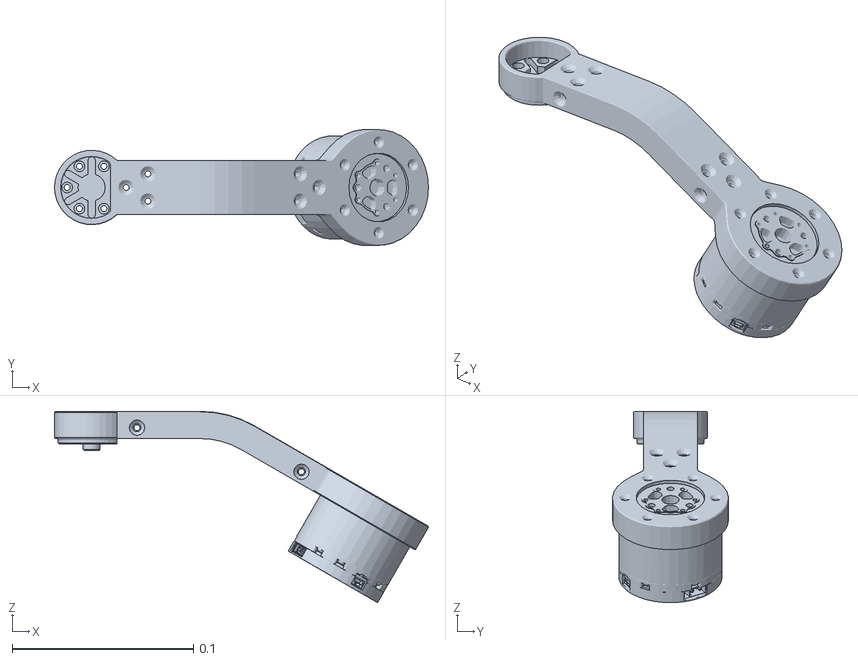
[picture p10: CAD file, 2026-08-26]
ubuntu/ros_jazzy/exo_identify/urdf/exo.SLDASM/meshes/link4.STL
0.206 x 0.0639 x 0.105

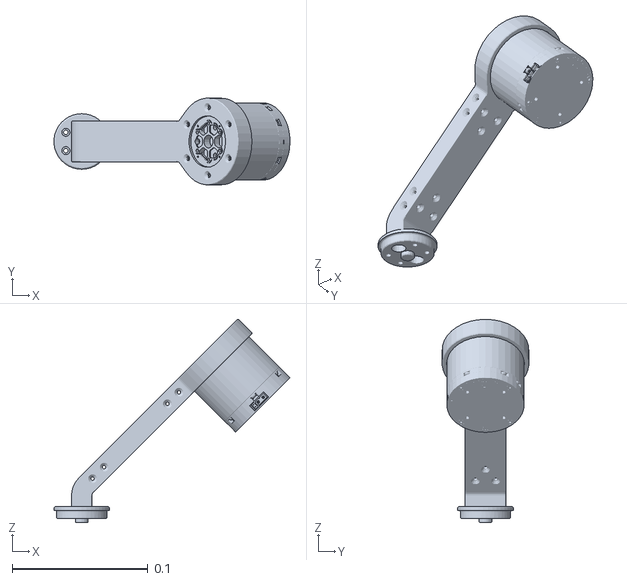
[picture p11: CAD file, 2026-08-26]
ubuntu/ros_jazzy/exo_identify/urdf/exo.SLDASM/meshes/link2.STL
0.174 x 0.0639 x 0.15

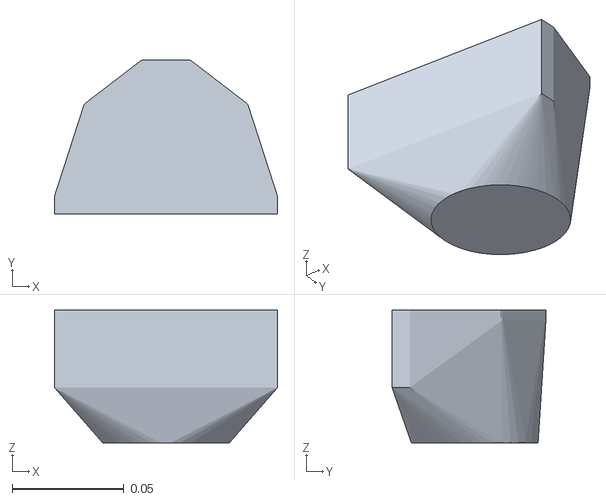
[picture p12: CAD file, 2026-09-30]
ubuntu/ros_jazzy/exo_identify/results/seven_dof/model_visualization/exo7_preview_sim_assets/base_link_1_collision_hull.stl
0.1 x 0.069 x 0.0595

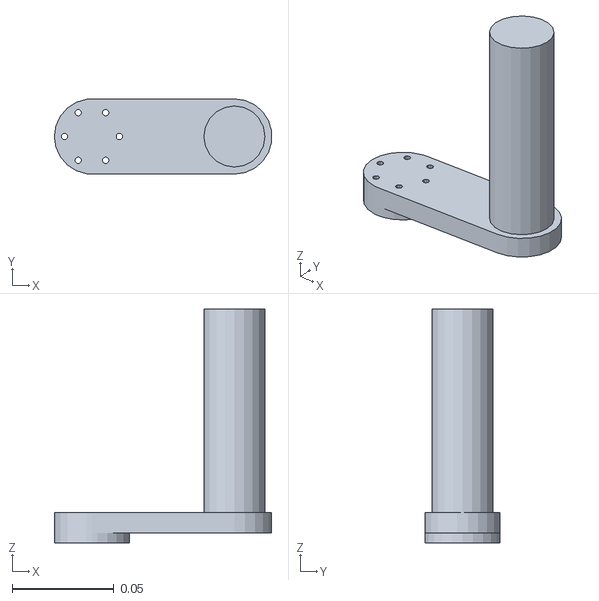
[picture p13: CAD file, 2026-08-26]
ubuntu/ros_jazzy/exo_identify/urdf/exo.SLDASM/meshes/link7.STL
0.107 x 0.037 x 0.115

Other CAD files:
ubuntu/ros_jazzy/exo_identify/results/seven_dof/model_visualization/exo7_preview_sim_assets/base_link.STL
ubuntu/ros_jazzy/exo_identify/results/seven_dof/model_visualization/exo7_preview_sim_assets/link1.STL
ubuntu/ros_jazzy/exo_identify/results/seven_dof/model_visualization/exo7_preview_sim_assets/link3_1_collision_hull.stl
ubuntu/ros_jazzy/exo_identify/results/seven_dof/model_visualization/exo7_preview_sim_assets/link4_part1.stl
ubuntu/ros_jazzy/exo_identify/results/seven_dof/model_visualization/exo7_preview_sim_assets/link4_part2.stl
ubuntu/ros_jazzy/exo_identify/results/seven_dof/model_visualization/exo7_preview_sim_assets/link5_part1.stl
ubuntu/ros_jazzy/exo_identify/results/seven_dof/model_visualization/exo7_preview_sim_assets/link5_part2.stl
ubuntu/ros_jazzy/exo_identify/results/seven_dof/model_visualization/exo7_preview_sim_assets/link6_part1.stl
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

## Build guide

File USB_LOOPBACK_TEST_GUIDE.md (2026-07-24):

# STM32 与 ROS Noetic USB CDC 回环测试说明

## 1. 测试目的

本测试用于验证以下 USB CDC 通信链路：

```text
Ubuntu 20.04 / ROS Noetic
        ↓
      USB CDC
        ↓
STM32 接收数据并原样返回
```

ROS 节点每秒发送一条短字符串，读取 STM32 返回的数据并进行比较。本测试只验证 USB 通信，不依赖 CAN 总线和电机。

> 建议关闭电机 48 V 电源，只连接 STM32 的 USB 数据线。

## 2. 分支和文件

| 电脑 | 开发分支 | 内容 |
|---|---|---|
| Windows | `windows-stm32` | STM32 工程和临时 USB 回环代码 |
| Ubuntu | `ubuntu-ros` | ROS Noetic 包和 Python 测试节点 |

ROS 测试节点：

```text
ubuntu/ros_noetic/d4340p_usb_bridge/scripts/usb_loopback_test.py
```

本测试面向 Ubuntu 20.04 + ROS Noetic。Ubuntu 26.04 不作为本次 ROS Noetic 测试环境。

## 3. 测试前同步代码

Windows 电脑保持在 `windows-stm32`：

```bash
git branch --show-current
git push origin windows-stm32
```

Ubuntu 电脑保持在 `ubuntu-ros`：

```bash
git branch --show-current
git pull origin ubuntu-ros
```

不要在 Windows 的日常 STM32 工作目录中切换到 `ubuntu-ros`。

## 4. Windows：编译并烧录 STM32

### 4.1 检查临时回环代码

文件：

```text
EXO2_DM_MOTOR/USB_DEVICE/App/usbd_cdc_if.c
```

`CDC_Receive_FS()` 中应调用：

```c
(void)CDC_Transmit_FS(Buf, (uint16_t)(*Len));
```

正式协议接收代码在测试期间保留为注释：

```c
/* USB_MotorComm_Receive(Buf, *Len); */
```

文件：

```text
EXO2_DM_MOTOR/Core/Src/main.c
```

正式反馈发送在测试期间保留为注释：

```c
/* (void)USB_MotorComm_SendFeedback(); */
```

关闭正式反馈可以避免二进制电机反馈帧和回环字符串混在一起。

### 4.2 烧录步骤

1. 用 Keil 打开 `EXO2_DM_MOTOR.uvprojx`。
2. 重新编译工程。
3. 将程序烧录到 STM32。
4. 烧录完成后重新连接 USB。
5. 本测试不需要连接 CAN 和电机。

## 5. Ubuntu：配置 ROS 测试环境

以下命令假设仓库位于 `~/EXO2_Workspace`。

### 5.1 检查分支和文件

```bash
cd ~/EXO2_Workspace
git branch --show-current
ls ubuntu/ros_noetic/d4340p_usb_bridge/scripts/usb_loopback_test.py
```

当前分支应显示：

```text
ubuntu-ros
```

### 5.2 安装依赖

```bash
sudo apt update
sudo apt install python3-serial
```

### 5.3 将 ROS 包加入 catkin 工作空间

```bash
source /opt/ros/noetic/setup.bash
mkdir -p ~/catkin_ws/src

ln -s ~/EXO2_Workspace/ubuntu/ros_noetic/d4340p_usb_bridge \
  ~/catkin_ws/src/d4340p_usb_bridge

cd ~/catkin_ws
catkin_make
source devel/setup.bash
```

如果软链接已经存在，不要重复执行 `ln -s`。

## 6. 检查 USB 设备和权限

连接 STM32 后执行：

```bash
ls /dev/ttyACM*
```

通常会显示：

```text
/dev/ttyACM0
```

长期使用建议加入 `dialout` 组：

```bash
sudo usermod -aG dialout $USER
```

执行后需要注销并重新登录。

仅用于当前测试时，也可以临时执行：

```bash
sudo chmod 666 /dev/ttyACM0
```

## 7. 启动回环测试

### 7.1 终端一：启动 ROS Master

```bash
source /opt/ros/noetic/setup.bash
roscore
```

### 7.2 终端二：启动测试节点

```bash
source /opt/ros/noetic/setup.bash
source ~/catkin_ws/devel/setup.bash

rosrun d4340p_usb_bridge usb_loopback_test.py \
  _port:=/dev/ttyACM0
```

正常时会持续显示：

```text
PASS: b'ROS_USB_TEST_000000\n'
PASS: b'ROS_USB_TEST_000001\n'
```

如果实际设备为 `/dev/ttyACM1`，将启动参数改为：

```bash
rosrun d4340p_usb_bridge usb_loopback_test.py \
  _port:=/dev/ttyACM1
```

### 7.3 终端三：查看 ROS 结果话题

```bash
source /opt/ros/noetic/setup.bash
source ~/catkin_ws/devel/setup.bash
rostopic echo /usb_loopback_test/ok
```

通信正常时会持续输出：

```text
data: True
---
```

## 8. 常见问题

### 找不到 `/dev/ttyACM0`

检查 USB 数据线、STM32 供电和 USB 接口，并在插拔设备前后分别执行：

```bash
ls /dev/ttyACM*
```

### 提示 `Permission denied`

临时执行：

```bash
sudo chmod 666 /dev/ttyACM0
```

或者加入 `dialout` 组后注销并重新登录。

### 提示缺少 `serial` 模块

```bash
sudo apt install python3-serial
```

### ROS 找不到 `d4340p_usb_bridge`

```bash
cd ~/catkin_ws
catkin_make
source devel/setup.bash
```

### 一直显示 `FAIL`，返回数据为空

检查：

- STM32 是否已经烧录临时回环程序；
- ROS 使用的串口设备是否正确；
- 串口是否被串口助手等程序占用；
- `CDC_Receive_FS()` 是否调用了 `CDC_Transmit_FS()`。

### 返回二进制杂乱数据

确认 `main.c` 中正式反馈发送已经暂时注释：

```c
/* (void)USB_MotorComm_SendFeedback(); */
```

## 9. 测试结束后恢复正式通信

在 `usbd_cdc_if.c` 中注释临时回环发送：

```c
/* (void)CDC_Transmit_FS(Buf, (uint16_t)(*Len)); */
```

恢复正式协议接收：

```c
USB_MotorComm_Receive(Buf, *Len);
```

在 `main.c` 中恢复正式反馈：

```c
(void)USB_MotorComm_SendFeedback();
```

然后重新编译并烧录 STM32。

如果临时回环仍对应独立提交 `ded3500`，也可以在 `windows-stm32` 执行：

```bash
git revert ded3500
```

`git revert` 会生成恢复提交，不会破坏已有 Git 历史。

## 10. 测试通过标准

同时满足以下条件即可认为 USB CDC 通信正常：

- Ubuntu 能识别对应的 `/dev/ttyACM*` 设备；
- 测试节点持续输出 `PASS`；
- `/usb_loopback_test/ok` 持续发布 `True`；
- 连续运行一段时间没有丢包或串口异常。

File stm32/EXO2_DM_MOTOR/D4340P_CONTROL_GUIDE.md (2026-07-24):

# D4340P control guide

The project initializes four 48 V D4340P motors on CAN1 at 1 Mbps. Motor IDs
are fixed at `0x01` through `0x04`, and Master ID is fixed at `0x000`.

The application intentionally does not enable a motor or send a motion command
at startup. After the mechanical assembly is secured and the emergency stop is
available, a typical MIT-mode sequence is:

```c
DM_D4340P_ClearError(&d4340p_motors[0]);
HAL_Delay(10U);
DM_D4340P_Enable(&d4340p_motors[0]);
HAL_Delay(10U);

/* Send periodically. For position control, kd must not be zero. */
DM_D4340P_MitControl(&d4340p_motors[0],
                     0.0f,   /* position, rad */
                     0.0f,   /* velocity, rad/s */
                     3.0f,   /* kp */
                     0.5f,   /* kd */
                     0.0f);  /* feedforward torque, N*m */
```

State feedback for motor `n` is stored by the CAN interrupt in
`d4340p_motors[n].feedback`. Check `status` before using the measurement in a
control loop.

The driver uses PMAX = 12.5 rad, VMAX = 20 rad/s, and TMAX = 28 N*m. These
values must match the motor settings. Configure the motors for MIT mode and
1 Mbps CAN with the Damiao host tool before use.

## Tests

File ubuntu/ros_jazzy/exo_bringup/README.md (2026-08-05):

# ROS 2 Jazzy `exo_bringup`

该功能包运行于 Ubuntu 24.04 + ROS 2 Jazzy，通过 USB CDC 与 `EXO2_DM_G474` 通讯，并提供7台达妙电机的控制、反馈、状态和温度接口。

- CAN ID 1～4：D4340P。
- CAN ID 5～7：D4310P。
- USB控制帧：156字节。
- USB反馈帧：114字节。
- 默认控制及反馈频率：500 Hz。
- 7台电机共享同一个全局控制模式：MIT模式或速度模式。

## 文件结构

```text
exo_bringup/
├── CMakeLists.txt
├── package.xml
├── LICENSE
├── README.md
├── launch/
│   └── dm_motor_usb.launch.py
└── scripts/
    ├── __init__.py
    ├── control_gui.py
    ├── node.py
    └── protocol.py
```

`node.py`负责ROS接口、串口收发和安全退出，`protocol.py`负责二进制帧、CRC16及反馈流解析，`control_gui.py`提供可选的图形化调试控制界面。

## 安装与编译

```bash
source /opt/ros/jazzy/setup.bash
mkdir -p ~/exo_ws/src
cp -r EXO2_Workspace/ubuntu/ros_jazzy/exo_bringup ~/exo_ws/src/
cd ~/exo_ws
rosdep install --from-paths src --ignore-src -r -y
colcon build --symlink-install --packages-select exo_bringup
source install/setup.bash
```

串口依赖及权限：

```bash
sudo apt update
sudo apt install python3-serial python3-tk
sudo usermod -aG dialout $USER
```

加入`dialout`后注销并重新登录。连接STM32后执行：

```bash
ls -l /dev/ttyACM*
```

## 启动

```bash
source /opt/ros/jazzy/setup.bash
source ~/exo_ws/install/setup.bash
ros2 launch exo_bringup dm_motor_usb.launch.py
```

同时启动可视化调试界面：

```bash
ros2 launch exo_bringup dm_motor_usb.launch.py use_gui:=true
```

`use_gui`默认为`false`，因此不指定时只启动USB桥接节点。GUI需要桌面图形环境和有效的`DISPLAY`变量。

GUI默认将两种电机的速度限制为±1.0 rad/s、前馈力矩限制为±1.0 N·m。位置范围保持为±12.5 rad。D4340P与D4310P的速度和力矩范围可以分别设置：

```bash
ros2 launch exo_bringup dm_motor_usb.launch.py use_gui:=true \
  gui_d4340_velocity_limit:=0.5 gui_d4340_torque_limit:=0.3 \
  gui_d4310_velocity_limit:=0.4 gui_d4310_torque_limit:=0.2
```

D4340P参数的最大允许值为20 rad/s和28 N·m，D4310P参数的最大允许值为30 rad/s和12.5 N·m；所有限制必须大于0。输入框和滑块使用对应型号的相同限幅，超出范围的输入会被截断到边界值。

覆盖串口或发送频率：

```bash
ros2 launch exo_bringup dm_motor_usb.launch.py \
  port:=/dev/ttyACM1 rate:=500.0
```

### 设置MIT模式的kp和kd

`kp`和`kd`都是长度必须为7的浮点数组，下标0～6对应CAN ID 1～7。固件允许的
范围为`0 <= kp <= 500`、`0 <= kd <= 5`。它们只在MIT模式中参与控制，速度
模式会忽略这两个参数。

通过launch在节点启动时设置：

```bash
ros2 launch exo_bringup dm_motor_usb.launch.py \
  kp:='[10.0,10.0,10.0,10.0,5.0,5.0,5.0]' \
  kd:='[0.5,0.5,0.5,0.5,0.2,0.2,0.2]'
```

节点运行期间可以动态修改，无需重启：

```bash
ros2 param set /dm_motor_usb kp \
  '[12.0,12.0,12.0,12.0,6.0,6.0,6.0]'
ros2 param set /dm_motor_usb kd \
  '[0.6,0.6,0.6,0.6,0.3,0.3,0.3]'
```

读取当前值：

```bash
ros2 param get /dm_motor_usb kp
ros2 param get /dm_motor_usb kd
```

数组长度、非有限数或超出固件范围的数值会被节点拒绝。失能时USB帧中的
`kp/kd`仍强制为零；运行期间设置的新值会保存在节点中，并在下次使能后使用。
修改已使能电机的增益会从下一帧立即生效，因此应先失能、修改参数、确认数值，
再使用安全目标重新使能。

也可直接运行节点：

```bash
ros2 run exo_bringup dm_motor_usb_node --ros-args \
  -p port:=/dev/ttyACM0 \
  -p rate:=500.0 \
  -p kp:='[0.0,0.0,0.0,0.0,0.0,0.0,0.0]' \
  -p kd:='[0.0,0.0,0.0,0.0,0.0,0.0,0.0]'
```

桥接节点已经运行时，也可以单独启动GUI：

```bash
ros2 run exo_bringup dm_motor_control_gui
```

## 可视化调试界面

GUI提供以下功能：

- 选择1～7号电机，并分别保存每台电机的位置、速度和前馈力矩目标。
- 每个控制量都支持输入框和滑块，发送时始终发布完整的7元素`JointState`。
- “发送一次”只发送一次当前目标；“持续发送”按照界面设置的0.1～100 Hz频率重复发布目标。
- MIT/速度模式切换。切换模式时自动发送失能并将全部目标清零。
- 显示7台电机的位置、速度、力矩、状态和温度反馈。
- “使能全部电机”需要二次确认；“失能并清零”和关闭窗口都会发送失能与全零目标。

GUI的持续发送频率不需要等于USB桥接节点的500 Hz。桥接节点会保存最近一次ROS目标，并独立以500 Hz向STM32发送。

> **安全提示：** GUI是调试工具，不能代替硬件急停。连续发送目标不会自动使能；使能操作作用于全部7台电机。MIT模式下位置控制还取决于桥接节点启动时配置的`kp`、`kd`。

## ROS接口

| 名称 | 类型 | 功能 |
|---|---|---|
| `/dm_motor_usb/command` | `sensor_msgs/msg/JointState` | 7台电机位置、速度和前馈力矩目标 |
| `/dm_motor_usb/enable` | `std_msgs/msg/Bool` | 同时使能或失能7台电机 |
| `/dm_motor_usb/control_mode` | `std_msgs/msg/UInt8` | 全局控制模式：0为MIT，1为速度模式 |
| `/dm_motor_usb/feedback` | `sensor_msgs/msg/JointState` | 位置、速度和力矩反馈 |
| `/dm_motor_usb/status` | `std_msgs/msg/UInt8MultiArray` | 7台电机状态码 |
| `/dm_motor_usb/temperature` | `std_msgs/msg/Float32MultiArray` | MOS和转子温度 |
| `/dm_motor_usb/clear_error` | `std_srvs/srv/Trigger` | 清除全部电机错误 |
| `/dm_motor_usb/set_zero` | `std_srvs/srv/Trigger` | 设置全部电机零点 |

数组下标0～6依次对应CAN ID 1～7。`JointState.name`依次为`d4340p_1`～`d4340p_4`、`d4310p_5`～`d4310p_7`。

## 控制模式

7台电机始终使用同一种全局控制模式，不能分别选择模式：

- `0`：MIT模式，使用`position`、`velocity`、`effort`以及节点参数`kp`、`kd`。
- `1`：速度模式，只使用`velocity`，STM32发送`0x200 + CAN ID`的速度控制帧。

切换模式会自动将`enable`置为`false`，并清零已保存的位置、速度和力矩目标。模式切换完成后，必须重新发送安全目标，再单独发送使能命令。

切换为速度模式：

```bash
ros2 topic pub --once /dm_motor_usb/control_mode \
  std_msgs/msg/UInt8 '{data: 1}'
```

发送7台电机的目标速度：

```bash
ros2 topic pub --once /dm_motor_usb/command sensor_msgs/msg/JointState \
  '{position: [0,0,0,0,0,0,0], velocity: [0.1,0.1,0.1,0.1,0.1,0.1,0.1], effort: [0,0,0,0,0,0,0]}'
```

切换回MIT模式：

```bash
ros2 topic pub --once /dm_motor_usb/control_mode \
  std_msgs/msg/UInt8 '{data: 0}'
```

切回MIT模式后，如果`kp`不为0，重新使能前应将每台电机的目标位置设置为其当前反馈位置，避免位置突变。

## 读取反馈

```bash
ros2 topic echo /dm_motor_usb/feedback
ros2 topic echo /dm_motor_usb/status
ros2 topic echo /dm_motor_usb/temperature
ros2 topic hz /dm_motor_usb/feedback
```

位置单位为rad，速度单位为rad/s，力矩单位为N·m。温度数组顺序为：

```text
[电机1 MOS, 电机1转子, ..., 电机7 MOS, 电机7转子]
```

## 安全控制测试

首次测试必须脱离人体和外骨骼负载，并准备硬件急停。先选择控制模式并确认电机处于失能状态，再发布完整7元素安全目标：

```bash
ros2 topic pub --once /dm_motor_usb/command sensor_msgs/msg/JointState \
  '{position: [0.0,0.0,0.0,0.0,0.0,0.0,0.0], velocity: [0.0,0.0,0.0,0.0,0.0,0.0,0.0], effort: [0.0,0.0,0.0,0.0,0.0,0.0,0.0]}'
```

清错、使能和失能：

```bash
ros2 service call /dm_motor_usb/clear_error std_srvs/srv/Trigger '{}'
ros2 topic pub --once /dm_motor_usb/enable std_msgs/msg/Bool '{data: true}'
ros2 topic pub --once /dm_motor_usb/enable std_msgs/msg/Bool '{data: false}'
```

设置零点前必须先失能、确认电机静止并位于机械零点：

```bash
ros2 service call /dm_motor_usb/set_zero std_srvs/srv/Trigger '{}'
```

使能时，节点保存最近一次完整目标并以500 Hz重复发送。失能时，节点仍以相同
频率发送有效USB命令帧，但会清除使能标志，并强制将位置、速度、`kp`、`kd`
和力矩全部置零，避免失能帧携带残留目标。退出时会发送3帧这样的失能全零
指令；STM32超过100 ms未收到有效命令也会自动失能，但软件保护不能代替硬件
急停。

注意：ROS节点持续发送失能全零USB帧，并不等于STM32会在CAN侧持续发送控制
帧。若电机只在收到CAN控制帧后返回反馈，失能状态下能否获得新的实时反馈由
STM32固件的失能分支决定；不能通过在ROS端伪造使能标志解决，否则电机实际会
进入使能状态。

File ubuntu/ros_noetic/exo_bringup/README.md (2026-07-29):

# ROS 1 Noetic `exo_bringup`

该功能包运行于 Ubuntu 20.04 + ROS 1 Noetic，通过 USB CDC 与 `EXO2_DM_G474` 通讯。接口、协议和电机数组映射与ROS 2版本一致。

- CAN ID 1～4：D4340P。
- CAN ID 5～7：D4310P。
- USB控制帧：156字节。
- USB反馈帧：114字节。
- 默认控制及反馈频率：500 Hz。
- 7台电机共享同一个全局控制模式：MIT模式或速度模式。

## 文件结构

```text
exo_bringup/
├── CMakeLists.txt
├── package.xml
├── LICENSE
├── README.md
├── launch/
│   └── dm_motor_usb.launch
└── scripts/
    ├── __init__.py
    ├── node.py
    └── protocol.py
```

## 安装与编译

```bash
source /opt/ros/noetic/setup.bash
mkdir -p ~/catkin_ws/src
cp -r EXO2_Workspace/ubuntu/ros_noetic/exo_bringup ~/catkin_ws/src/
cd ~/catkin_ws
catkin_make
source devel/setup.bash
```

安装串口依赖并配置权限：

```bash
sudo apt update
sudo apt install python3-serial
sudo usermod -aG dialout $USER
```

加入`dialout`后注销并重新登录。

## 启动

终端一：

```bash
source /opt/ros/noetic/setup.bash
roscore
```

终端二：

```bash
source /opt/ros/noetic/setup.bash
source ~/catkin_ws/devel/setup.bash
roslaunch exo_bringup dm_motor_usb.launch
```

覆盖串口或发送频率：

```bash
roslaunch exo_bringup dm_motor_usb.launch \
  port:=/dev/ttyACM1 rate:=500.0
```

也可直接运行：

```bash
rosrun exo_bringup node.py \
  _port:=/dev/ttyACM0 \
  _rate:=500.0 \
  _kp:='[0.0,0.0,0.0,0.0,0.0,0.0,0.0]' \
  _kd:='[0.0,0.0,0.0,0.0,0.0,0.0,0.0]'
```

## ROS接口

| 名称 | 类型 | 功能 |
|---|---|---|
| `/dm_motor_usb/command` | `sensor_msgs/JointState` | 7台电机位置、速度和前馈力矩目标 |
| `/dm_motor_usb/enable` | `std_msgs/Bool` | 同时使能或失能7台电机 |
| `/dm_motor_usb/control_mode` | `std_msgs/UInt8` | 全局控制模式：0为MIT，1为速度模式 |
| `/dm_motor_usb/feedback` | `sensor_msgs/JointState` | 位置、速度和力矩反馈 |
| `/dm_motor_usb/status` | `std_msgs/UInt8MultiArray` | 7台电机状态码 |
| `/dm_motor_usb/temperature` | `std_msgs/Float32MultiArray` | MOS和转子温度 |
| `/dm_motor_usb/clear_error` | `std_srvs/Trigger` | 清除全部电机错误 |
| `/dm_motor_usb/set_zero` | `std_srvs/Trigger` | 设置全部电机零点 |

数组下标0～6依次对应CAN ID 1～7。

## 控制模式

7台电机始终使用同一种全局控制模式：

- `0`：MIT模式，使用`position`、`velocity`、`effort`以及节点参数`kp`、`kd`。
- `1`：速度模式，只使用`velocity`。

切换模式会自动失能7台电机并清零节点保存的目标值。切换后必须重新发送安全目标，再重新使能。

```bash
# 切换为速度模式
rostopic pub -1 /dm_motor_usb/control_mode std_msgs/UInt8 'data: 1'

# 发送7台电机速度目标
rostopic pub -1 /dm_motor_usb/command sensor_msgs/JointState \
'{position: [0,0,0,0,0,0,0], velocity: [0.1,0.1,0.1,0.1,0.1,0.1,0.1], effort: [0,0,0,0,0,0,0]}'

# 切换回MIT模式
rostopic pub -1 /dm_motor_usb/control_mode std_msgs/UInt8 'data: 0'
```

切回MIT模式后，如果`kp`不为0，重新使能前应将目标位置设置为当前反馈位置。

## 读取反馈

```bash
rostopic echo /dm_motor_usb/feedback
rostopic echo /dm_motor_usb/status
rostopic echo /dm_motor_usb/temperature
rostopic hz /dm_motor_usb/feedback
```

## 安全控制测试

首次测试必须脱离人体和外骨骼负载，先选择控制模式并保持电机失能，同时准备硬件急停。

```bash
rostopic pub -1 /dm_motor_usb/command sensor_msgs/JointState \
'{position: [0,0,0,0,0,0,0], velocity: [0,0,0,0,0,0,0], effort: [0,0,0,0,0,0,0]}'

rosservice call /dm_motor_usb/clear_error '{}'
rostopic pub -1 /dm_motor_usb/enable std_msgs/Bool 'data: true'
rostopic pub -1 /dm_motor_usb/enable std_msgs/Bool 'data: false'
```

设置零点前必须失能并保证电机完全静止：

```bash
rosservice call /dm_motor_usb/set_zero '{}'
```

节点保存最近一次完整目标并以500 Hz重复发送。退出时会发送3帧失能指令；STM32超过100 ms未收到有效命令也会自动失能，但软件保护不能代替硬件急停。

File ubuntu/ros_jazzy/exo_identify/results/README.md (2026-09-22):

# Identification Results

This directory contains reproducible data and artifacts generated by the
`exo_identify` package. The source code remains in the package-level
`scripts/`, `config/`, `launch/`, and `urdf/` directories.

## Layout

```text
results/
├── seven_dof/                  # Current seven-DOF outputs
│   ├── excitation/             # Designed excitation trajectories and reports
│   ├── simulation_data/        # MuJoCo forward-simulation CSV data (*_sim files)
│   ├── simulation_model/       # Generated MJCF model and mesh assets
│   ├── model_visualization/    # Preview MJCF/PNG files (PNG is opt-in)
│   ├── dynamics_identification/# Identified parameters; `_sim` marks simulation
│   ├── compensation_validation/# Independent gravity/friction validation
│   ├── neural_identification/  # Optional NumPy neural-model outputs
│   └── hardware_experiments/   # Raw and processed real-hardware recordings
└── two_dof/                    # Historical two-DOF results; not valid for seven DOF
```

The default output locations are inside this directory so that experiment
artifacts can be reviewed and versioned together with the package. Pass an
explicit `--output-dir` or ROS parameter when a run should be stored elsewhere.

Physical motor-to-joint calibration is kept separately in
`../config/hardware_mapping.yaml` and is shared by both real-hardware nodes.

The shared trajectory in `seven_dof/excitation/` is used by both simulation and
hardware. Simulation collection files use the `_sim` suffix; hardware runs are
stored separately under `hardware_experiments/` and do not reuse simulation
files.

The complete simulation keeps each stage's artifacts in its own directory:
`simulation_data/` contains forward-simulation CSV files, `simulation_model/`
contains the generated MJCF and mesh assets, `dynamics_identification/` contains
identified parameters and the exported gravity formula, and
`compensation_validation/` contains the independent deployment precheck. All
simulation artifacts use the `_sim` suffix. Model-preview outputs are kept in
`model_visualization/`; a PNG is generated only when `mujoco_model.py --preview`
is requested. The checked-in MuJoCo models use relative mesh paths so they can be
loaded after cloning the repository on another machine.

The CSV files in `simulation_data/` are produced by a live MuJoCo forward
simulation. A position/velocity virtual servo applies the command, `mj_step`
advances the model, and the collector records the resulting joint state and
`qfrc_actuator`; configurable control, external-torque, and sensor noise is
stored in `simulation_metadata_sim.json`.

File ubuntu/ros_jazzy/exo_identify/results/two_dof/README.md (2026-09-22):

# Historical two-DOF results

This directory archives outputs produced by the former two-joint test mechanism.
They are retained for traceability only and are not compatible with the current
seven-joint CSV schemas, parameter files, or neural-model format.

Do not use these files as inputs to the seven-DOF pipeline. New runs write under
`results/seven_dof/` by default.

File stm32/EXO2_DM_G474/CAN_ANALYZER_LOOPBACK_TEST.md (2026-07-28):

# CAN 分析仪收发测试

本测试用于检查 STM32G474、CAN FD 收发器、总线接线以及 CAN 分析仪之间的双向通信。

## 安全准备

测试时先断开 7 台电机，或至少断开电机动力电源，避免测试帧被电机误处理。总线两端各保留一个 120 Ω 终端电阻，断电测量 CAN_H 与 CAN_L 之间应约为 60 Ω。

## CAN 分析仪参数

- 工作模式：Normal / Active，不要选择 Listen Only
- 帧格式：CAN FD with Bit Rate Switching（BRS）
- 仲裁段波特率：1 Mbit/s
- 数据段波特率：4 Mbit/s
- 标识符：Standard ID（11 位）
- 数据长度：8 字节

这些参数必须和 CubeMX 中的 FDCAN1 配置一致。

## STM32 主动发送测试

烧录并复位后，分析仪应每 100 ms 收到一帧：

- CAN ID：`0x100`
- 帧类型：CAN FD + BRS，数据帧
- DLC：8
- 数据：`A5 5A XX XX XX XX 47 34`

第 2～5 字节是小端格式的 32 位递增计数器。例如，开始几帧应为：

```text
A5 5A 00 00 00 00 47 34
A5 5A 01 00 00 00 47 34
A5 5A 02 00 00 00 47 34
```

能连续收到这些帧，说明 STM32 到分析仪的发送链路正常。

## 分析仪发送与 STM32 回传测试

从分析仪发送以下帧：

- CAN ID：`0x200`
- 帧类型：CAN FD + BRS，数据帧
- DLC：8
- 示例数据：`01 02 03 04 05 06 07 08`

STM32 收到后应立即回传：

- CAN ID：`0x201`
- 数据：与收到的 8 字节完全相同

示例回传为 `01 02 03 04 05 06 07 08`。能收到回传说明分析仪到 STM32 的接收链路也正常。

## 恢复正常电机控制

打开 `Core/Inc/main.h`，把：

```c
#define CAN_ANALYZER_LOOPBACK_TEST  1U
```

改为：

```c
#define CAN_ANALYZER_LOOPBACK_TEST  0U
```

然后重新编译并烧录。设为 `0U` 后会恢复原来的 USB 通信、500 Hz 定时控制和 7 台电机控制代码，不需要删除本次加入的测试函数。

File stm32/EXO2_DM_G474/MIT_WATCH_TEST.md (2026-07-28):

# Keil Watch单电机MIT测试

当前工程中 `MIT_WATCH_TEST_MODE` 已设为 `1U`。该模式暂停USB上位机控制，只通过Keil Debug的Watch窗口控制一台电机，MIT控制帧频率为500 Hz。

## 安全准备

首次测试应卸载或架空电机输出端，并准备快速断开48 V动力电源。上电时所有控制量为0，电机默认不使能。确保电机已经设置为MIT模式，CAN ID与测试ID一致。

## 加入Watch的变量

```text
mit_watch_motor_id
mit_watch_enable_request
mit_watch_clear_error_request
mit_watch_set_zero_request
mit_watch_motor_enabled
mit_watch_last_status
mit_watch_position
mit_watch_velocity
mit_watch_kp
mit_watch_kd
mit_watch_torque
dm_motors[0].feedback.status
dm_motors[0].feedback.position
dm_motors[0].feedback.velocity
dm_motors[0].feedback.torque
dm_motors[0].feedback.mos_temperature
dm_motors[0].feedback.rotor_temperature
```

`mit_watch_motor_id`默认为1。测试其他电机时，必须先失能，确认 `mit_watch_motor_enabled`为0，再修改ID。若选择2号电机，反馈数组下标应改为1，依此类推。

`mit_watch_last_status`的值为：0表示HAL_OK，1表示HAL_ERROR，2表示HAL_BUSY，3表示HAL_TIMEOUT。

## 操作顺序

1. 保持 `mit_watch_enable_request = 0`。
2. 先设置安全控制量：位置和速度目标为0，Kp、Kd和转矩也为0。
3. 需要清错时，将 `mit_watch_clear_error_request`改成1，程序执行一次后自动清零。
4. 需要设置零点时，保持电机失能，将 `mit_watch_set_zero_request`改成1，程序执行一次后自动清零。
5. 将 `mit_watch_enable_request`改成1。使能成功后，`mit_watch_motor_enabled`变为1。
6. 从很小的Kp、Kd或转矩开始逐步修改，不要直接输入较大数值。
7. 测试结束时，先把Kp和转矩改为0，再将 `mit_watch_enable_request`改成0。
8. 确认 `mit_watch_motor_enabled`变成0后再断开电源。

调试器暂停CPU时，500 Hz控制帧也会停止，因此不要把暂停按钮作为唯一安全措施。

## 恢复正常控制

在 `Core/Inc/main.h` 中改为：

```c
#define MIT_WATCH_TEST_MODE  0U
```

重新编译并烧录后，即恢复USB上位机和7台电机控制。

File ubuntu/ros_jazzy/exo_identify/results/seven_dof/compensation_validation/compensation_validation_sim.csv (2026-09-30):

t | gravity1_reference | gravity2_reference | gravity3_reference | gravity4_reference | gravity5_reference | gravity6_reference | gravity7_reference | gravity1_predicted | gravity2_predicted | gravity3_predicted | gravity4_predicted | gravity5_predicted | gravity6_predicted | gravity7_predicted | gravity1_error | gravity2_error | gravity3_error | gravity4_error | gravity5_error | gravity6_error | gravity7_error | friction1_reference | friction2_reference | friction3_reference | friction4_reference | friction5_reference | friction6_reference | friction7_reference | friction1_predicted | friction2_predicted | friction3_predicted | friction4_predicted | friction5_predicted | friction6_predicted | friction7_predicted | friction1_error | friction2_error | friction3_error | friction4_error | friction5_error | friction6_error | friction7_error | compensation1_reference | compensation2_reference | compensation3_reference | compensation4_reference | compensation5_reference | compensation6_reference | compensation7_reference | compensation1_predicted | compensation2_predicted | compensation3_predicted | compensation4_predicted | compensation5_predicted | compensation6_predicted |
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

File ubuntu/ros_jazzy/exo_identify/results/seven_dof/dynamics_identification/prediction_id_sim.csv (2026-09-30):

t | tau1_measured | tau2_measured | tau3_measured | tau4_measured | tau5_measured | tau6_measured | tau7_measured | tau1_predicted | tau2_predicted | tau3_predicted | tau4_predicted | tau5_predicted | tau6_predicted | tau7_predicted | error1 | error2 | error3 | error4 | error5 | error6 | error7
0.000000000000000000e+00 | 0.000000000000000000e+00 | 0.000000000000000000e+00 | 0.000000000000000000e+00 | 0.000000000000000000e+00 | 0.000000000000000000e+00 | 0.000000000000000000e+00 | 0.000000000000000000e+00 | -1.303584046093796966e-01 | 3.170318163322882743e-02 | -1.462830938423337057e-01 | 2.667987224634860155e-02 | 4.548733835503014911e-01 | -4.771486838125280072e-01 | 4.198418505564394110e-01 | -1.303584046093796966e-01 | 3.170318163322882743e-02 | -1.462830938423337057e-01 | 2.667987224634860155e-02 | 4.548733835503014911e-01 | -4.771486838125280072e-01 | 4.198418505564394110e-01
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

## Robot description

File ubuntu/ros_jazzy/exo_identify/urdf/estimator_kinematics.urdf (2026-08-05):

<?xml version="1.0" encoding="utf-8"?>
<!-- Kinematics only: inertial, visual and collision data are intentionally absent. -->
<robot name="exo_2dof_estimator">
  <link name="base_link"/>
  <link name="link1"/>
  <joint name="joint1" type="continuous">
    <origin xyz="0 0 0" rpy="0 0 0"/>
    <parent link="base_link"/>
    <child link="link1"/>
    <axis xyz="0 0 1"/>
  </joint>
  <link name="link2"/>
  <joint name="joint2" type="continuous">
    <origin xyz="0.09 0 0.12" rpy="0 1.5708 0"/>
    <parent link="link1"/>
    <child link="link2"/>
    <axis xyz="0 0 1"/>
  </joint>
</robot>

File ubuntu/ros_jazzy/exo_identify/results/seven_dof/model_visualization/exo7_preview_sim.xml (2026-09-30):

<?xml version='1.0' encoding='utf-8'?>
<mujoco model="exo7">
  <compiler angle="radian" autolimits="true" balanceinertia="true" inertiafromgeom="false" />
  <option timestep="0.002" gravity="0 0 -9.81" integrator="implicitfast">
    <flag multiccd="enable" />
  </option>
  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
  <default>
    <joint damping="0" armature="0" />
    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
  </default>
  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
  <worldbody>
    <light name="key" pos="0 -2 3" dir="0 0.5 -1" diffuse="0.8 0.8 0.8" />
    <light name="fill" pos="1 2 2" dir="-0.4 -0.5 -1" diffuse="0.45 0.45 0.45" />
    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
    <body name="base_link" pos="0 0 0.2" quat="0.707105482511 0.707108079859 0 0">
      <inertial pos="-2.76522939481e-05 -0.00626400392937 -0.0205338832218" mass="0.158842788893151" fullinertia="5.54652310554e-05 7.62543275606e-05 9.62565645866e-05 2.59684158939e-08 -1.91637415591e-09 -4.14314945804e-06" />
      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
      <body name="link1" pos="0 0 0" quat="1 0 0 0">
        <joint name="joint1" type="hinge" axis="0 0 1" limited="false" damping="0.4" armature="0.002" frictionloss="0.15" />
        <inertial pos="0.192543499762 -9.19221949391e-06 0.0960725879689" mass="0.223146328060751" fullinertia="9.5841749296e-05 0.000155145529079 0.000137025472039 9.10803390733e-09 -1.00270837592e-05 1.93841799728e-08" />
        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
        <body name="link2" pos="0.217 0 0.143" quat="0.707105482511 0 -0.707108079859 0">
          <joint name="joint2" type="hinge" axis="0 0 1" limited="false" damping="0.4" armature="0.002" frictionloss="0.15" />
          <inertial pos="0.0863857199363 -1.1738382372e-05 0.0898358709478" mass="0.1747501382594" fullinertia="6.93110438363e-05 7.08196541227e-05 6.87606880985e-05 2.01471665279e-08 -2.11345670842e-05 7.26637652826e-09" />
          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
          <body name="link3" pos="0.093408 0 0.1236" quat="0.923879181092 0 -0.382684280765 0">
            <joint name="joint3" type="hinge" axis="0 0 1" limited="false" damping="0.4" armature="0.002" frictionloss="0.15" />
            <inertial pos="0.217004642679 2.83916312927e-05 0.00764645069754" mass="0.195695773240529" fullinertia="5.22557069199e-05 0.000218097395443 0.000238890923335 -4.53524188604e-08 -2.08112687785e-06 -5.79147294733e-09" />
            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
            <body name="link4" pos="0.28 0 0.02525" quat="1 0 0 0">
              <joint name="joint4" type="hinge" axis="0 0 1" limited="false" damping="0.4" armature="0.002" frictionloss="0.15" />
              <inertial pos="0.12147524619 3.04089991704e-05 -0.0342250620338" mass="0.166986707079527" fullinertia="5.10861078173e-05 7.72686179756e-05 9.01471064405e-05 6.9779713404e-08 1.65877290301e-05 -4.61760199067e-08" />
              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
              <body name="link5" pos="0.15754 0 -0.030804" quat="0.96592566784 0 0.258819636443 0">
                <joint name="joint5" type="hinge" axis="0 0 1" limited="false" damping="0.4" armature="0.002" frictionloss="0.15" />
                <inertial pos="0.10226757507 3.09456472451e-05 0.0677487506851" mass="0.164079361843354" fullinertia="6.73397754765e-05 6.64626574943e-05 6.24705968424e-05 4.61750759704e-08 -1.72031156638e-05 6.97786745632e-08" />
                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
                <body name="link6" pos="0.10546 0 0.094317" quat="0.866024791583 0 -0.500001060363 0">
                  <joint name="joint6" type="hinge" axis="0 0 1" limited="false" damping="0.4" armature="0.002" frictionloss="0.15" />
                  <inertial pos="0.102176943657 2.81709402693e-05 0.0902037061729" mass="0.180239914092338" fullinertia="8.60256737789e-05 8.11053180406e-05 6.13417260945e-05 5.09959760074e-09 -9.85407862845e-06 8.35176163929e-08" />
                  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
                  <body name="link7" pos="0.102 0 0.12168" quat="0.707105482511 0 -0.707108079859 0">
                    <joint name="joint7" type="hinge" axis="0 0 1" limited="false" damping="0.4" armature="0.002" frictionloss="0.15" />
                    <inertial pos="0.0556373148324 1.42355745247e-16 0.0443709660148" mass="0.11199016304375" fullinertia="0.000149273764531 0.000220568333963 8.7783329166e-05 -3.06329398917e-20 -5.79807500967e-05 -4.74943652813e-20" />
                    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
                  </body>
                </body>
              </body>
            </body>
          </body>
        </body>
      </body>
    </body>
  </worldbody>
  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
  <actuator>
    <motor name="joint1_motor" joint="joint1" gear="1" />
    <motor name="joint2_motor" joint="joint2" gear="1" />
    <motor name="joint3_motor" joint="joint3" gear="1" />
    <motor name="joint4_motor" joint="joint4" gear="1" />
    <motor name="joint5_motor" joint="joint5" gear="1" />
    <motor name="joint6_motor" joint="joint6" gear="1" />
    <motor name="joint7_motor" joint="joint7" gear="1" />
  </actuator>
</mujoco>

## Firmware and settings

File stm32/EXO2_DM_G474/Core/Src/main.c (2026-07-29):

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
/* Includes ------------------------------------------------------------------*/
#include "main.h"
#include "fdcan.h"
#include "tim.h"
#include "usb_device.h"
#include "gpio.h"

/* USER CODE BEGIN Includes */
#include <dm_motor.h>
#include <usb_motor_comm.h>

/* USER CODE END Includes */

/* USER CODE BEGIN PTD */
typedef enum
{
  MOTOR_MODE_SWITCH_IDLE = 0U,
  MOTOR_MODE_SWITCH_DISABLE,
  MOTOR_MODE_SWITCH_WRITE,
  MOTOR_MODE_SWITCH_WAIT,
  MOTOR_MODE_SWITCH_ENABLE
} Motor_ModeSwitchState_t;

/* USER CODE END PTD */

/* USER CODE BEGIN PD */
#define MOTOR_ACTION_CLEAR_ERROR  0x01U
#define MOTOR_ACTION_SET_ZERO     0x02U
#define MOTOR_ACTION_ENABLE       0x04U
#define MOTOR_ACTION_DISABLE      0x08U

#define MOTOR_MODE_SWITCH_WAIT_MS  10U

/* USER CODE END PD */


/* USER CODE BEGIN PV */
static USB_MotorCommand_t motor_command;
static volatile uint8_t motor_enabled[DM_MOTOR_COUNT];
static uint8_t motor_action_pending[DM_MOTOR_COUNT];
static uint8_t motor_action_index;
static volatile uint8_t motor_control_index;
static volatile uint8_t feedback_pending;
static volatile uint8_t usb_command_received;
static volatile uint8_t motor_control_suspended;
static volatile DM_ControlMode_t active_control_mode = DM_CONTROL_MODE_MIT;
static DM_ControlMode_t requested_control_mode = DM_CONTROL_MODE_MIT;
static DM_ControlMode_t mode_switch_target = DM_CONTROL_MODE_MIT;
static Motor_ModeSwitchState_t mode_switch_state = MOTOR_MODE_SWITCH_IDLE;
static uint8_t control_mode_initialized;
static uint8_t mode_switch_index;
static uint8_t mode_restore_enabled[DM_MOTOR_COUNT];
static uint32_t mode_switch_wait_tick;
static uint32_t last_usb_command_tick;
static uint32_t can_test_last_tick;
static uint32_t can_test_counter;
static volatile uint8_t can_test_enabled = CAN_ANALYZER_LOOPBACK_TEST;
static volatile uint8_t mit_watch_test_enabled = MIT_WATCH_TEST_MODE;
static volatile uint8_t mit_watch_active_motor_index;
static volatile uint8_t mit_watch_timer_divider;

/* Variables available directly in the Keil debugger Watch window. */
volatile uint8_t mit_watch_motor_id = 1U;
volatile uint8_t mit_watch_enable_request;
volatile uint8_t mit_watch_clear_error_request;
volatile uint8_t mit_watch_set_zero_request;
volatile uint8_t mit_watch_motor_enabled;
volatile uint32_t mit_watch_last_status = HAL_OK;
volatile float mit_watch_position;
volatile float mit_watch_velocity;
volatile float mit_watch_kp;
volatile float mit_watch_kd;
volatile float mit_watch_torque;

/* USER CODE END PV */

void SystemClock_Config(void);
/* USER CODE BEGIN PFP */
static void Motor_ProcessPendingAction(void);
static void Motor_StartControlModeSwitch(DM_ControlMode_t mode);
static void Motor_ProcessControlModeSwitch(void);
static void MIT_WatchTestProcess(void);

/* USER CODE END PFP */

/* USER CODE BEGIN 0 */
static void Motor_ProcessPendingAction(void)
{
  HAL_StatusTypeDef status;
  uint32_t interrupt_state;
  uint8_t action;
  uint8_t index;
  uint8_t offset;

  for (offset = 0U; offset < DM_MOTOR_COUNT; ++offset)
  {
    index = (uint8_t)((motor_action_index + offset) % DM_MOTOR_COUNT);
    action = motor_action_pending[index];
    if (action == 0U)
    {
      continue;
    }

    interrupt_state = __get_PRIMASK();
    __disable_irq();

    if ((action & MOTOR_ACTION_CLEAR_ERROR) != 0U)
    {
      status = DM_Motor_ClearError(&dm_motors[index]);
      action = MOTOR_ACTION_CLEAR_ERROR;
    }
    else if ((action & MOTOR_ACTION_SET_ZERO) != 0U)
    {
      status = DM_Motor_SetZero(&dm_motors[index]);
      action = MOTOR_ACTION_SET_ZERO;
    }
    else if ((action & MOTOR_ACTION_DISABLE) != 0U)
    {
      status = DM_Motor_Disable(&dm_motors[index]);
      action = MOTOR_ACTION_DISABLE;
    }
    else
    {
      status = DM_Motor_Enable(&dm_motors[index]);
      action = MOTOR_ACTION_ENABLE;
    }

    if (interrupt_state == 0U)
    {
      __enable_irq();
    }

    if (status == HAL_OK)
    {
      motor_action_pending[index] &= (uint8_t)~action;
      if (action == MOTOR_ACTION_ENABLE)
      {
        motor_enabled[index] = 1U;
      }
    }

    motor_action_index = index + 1U;
    if (motor_action_index >= DM_MOTOR_COUNT)
    {
      motor_action_index = 0U;
    }
    return;
  }
}

static void Motor_StartControlModeSwitch(DM_ControlMode_t mode)
{
  uint8_t index;

  motor_control_suspended = 1U;
  mode_switch_target = mode;
  mode_switch_index = 0U;
  mode_switch_state = MOTOR_MODE_SWITCH_DISABLE;

  for (index = 0U; index < DM_MOTOR_COUNT; ++index)
  {
    mode_restore_enabled[index] = motor_enabled[index];
    motor_enabled[index] = 0U;
    motor_action_pending[index] &=
      (uint8_t)~(MOTOR_ACTION_ENABLE | MOTOR_ACTION_DISABLE);
  }
}

static void Motor_ProcessControlModeSwitch(void)
{
  HAL_StatusTypeDef status;
  uint32_t interrupt_state;
  uint8_t should_enable;

  if (mode_switch_state == MOTOR_MODE_SWITCH_IDLE)
  {
    return;
  }

  if (mode_switch_state == MOTOR_MODE_SWITCH_WAIT)
  {
    if ((HAL_GetTick() - mode_switch_wait_tick) <
        MOTOR_MODE_SWITCH_WAIT_MS)
    {
      return;
    }

    active_control_mode = mode_switch_target;
    control_mode_initialized = 1U;
    mode_switch_index = 0U;
    mode_switch_state = MOTOR_MODE_SWITCH_ENABLE;
    return;
  }

  if (mode_switch_state == MOTOR_MODE_SWITCH_ENABLE)
  {
    should_enable =
      ((mode_restore_enabled[mode_switch_index] != 0U) &&
       (usb_command_received != 0U) &&
       ((motor_command.motor[mode_switch_index].flags &
         USB_MOTOR_FLAG_ENABLE) != 0U)) ? 1U : 0U;

    if (should_enable == 0U)
    {
      status = HAL_OK;
    }
    else
    {
      interrupt_state = __get_PRIMASK();
      __disable_irq();
      status = DM_Motor_Enable(&dm_motors[mode_switch_index]);
      if (interrupt_state == 0U)
      {
        __enable_irq();
      }
    }

    if (status != HAL_OK)
    {
      return;
    }

    motor_enabled[mode_switch_index] = should_enable;
    ++mode_switch_index;
    if (mode_switch_index >= DM_MOTOR_COUNT)
    {
      mode_switch_state = MOTOR_MODE_SWITCH_IDLE;
      motor_control_suspended = 0U;
    }
    return;
  }

  interrupt_state = __get_PRIMASK();
  __disable_irq();
  if (mode_switch_state == MOTOR_MODE_SWITCH_DISABLE)
  {
    status = DM_Motor_Disable(&dm_motors[mode_switch_index]);
  }
  else
  {
    status = DM_Motor_SetControlMode(&dm_motors[mode_switch_index],
                                     mode_switch_target);
  }
  if (interrupt_state == 0U)
  {
    __enable_irq();
  }

  if (status != HAL_OK)
  {
    return;
  }

  ++mode_switch_index;
  if (mode_switch_index < DM_MOTOR_COUNT)
  {
    return;
  }

  mode_switch_index = 0U;
  if (mode_switch_state == MOTOR_MODE_SWITCH_DISABLE)
  {
    mode_switch_state = MOTOR_MODE_SWITCH_WRITE;
  }
  else
  {
    mode_switch_wait_tick = HAL_GetTick();
    mode_switch_state = MOTOR_MODE_SWITCH_WAIT;
  }
}

static void MIT_WatchTestProcess(void)
{
  HAL_StatusTypeDef status;
  uint32_t interrupt_state;
  uint8_t selected_index;

  if ((mit_watch_motor_id == 0U) ||
      (mit_watch_motor_id > DM_MOTOR_COUNT))
  {
    mit_watch_last_status = HAL_ERROR;
    return;
  }

  selected_index = mit_watch_motor_id - 1U;

  if (mit_watch_clear_error_request != 0U)
  {
    mit_watch_clear_error_request = 0U;
    interrupt_state = __get_PRIMASK();
    __disable_irq();
    status = DM_Motor_ClearError(&dm_motors[selected_index]);
    if (interrupt_state == 0U)
    {
      __enable_irq();
    }
    mit_watch_last_status = status;
  }

  if (mit_watch_set_zero_request != 0U)
  {
    mit_watch_set_zero_request = 0U;
    interrupt_state = __get_PRIMASK();
    __disable_irq();
    status = DM_Motor_SetZero(&dm_motors[selected_index]);
    if (interrupt_state == 0U)
    {
      __enable_irq();
    }
    mit_watch_last_status = status;
  }

  if ((mit_watch_enable_request != 0U) &&
      (mit_watch_motor_enabled == 0U))
  {
    interrupt_state = __get_PRIMASK();
    __disable_irq();
    status = DM_Motor_Enable(&dm_motors[selected_index]);
    if (status == HAL_OK)
    {
      mit_watch_active_motor_index = selected_index;
      mit_watch_motor_enabled = 1U;
    }
    if (interrupt_state == 0U)
    {
      __enable_irq();
    }
    mit_watch_last_status = status;
  }
  else if ((mit_watch_enable_request == 0U) &&
           (mit_watch_motor_enabled != 0U))
  {
    interrupt_state = __get_PRIMASK();
    __disable_irq();
    status = DM_Motor_Disable(
      &dm_motors[mit_watch_active_motor_index]);
    if (status == HAL_OK)
    {
      mit_watch_motor_enabled = 0U;
    }
    if (interrupt_state == 0U)
    {
      __enable_irq();
    }
    mit_watch_last_status = status;
  }
}

/* USER CODE END 0 */

/**
  * @brief  The application entry point.
  * @retval int
  */
int main(void)
{

  /* USER CODE BEGIN 1 */
  FDCAN_FilterTypeDef fdcan_filter;

  /* USER CODE END 1 */

  /* MCU Configuration--------------------------------------------------------*/

  /* Reset of all peripherals, Initializes the Flash interface and the Systick. */
  HAL_Init();

  /* Configure the system clock */
  SystemClock_Config();

  /* Initialize all configured peripherals */
  MX_GPIO_Init();
  MX_FDCAN1_Init();
  MX_TIM6_Init();
  MX_USB_Device_Init();
  /* USER CODE BEGIN 2 */
  fdcan_filter.IdType = FDCAN_STANDARD_ID;
  fdcan_filter.FilterIndex = 0U;
  fdcan_filter.FilterType = FDCAN_FILTER_MASK;
  fdcan_filter.FilterConfig = FDCAN_FILTER_TO_RXFIFO0;
  fdcan_filter.FilterID1 = (can_test_enabled != 0U) ? 0x200U : 0U;
  /* Temporary diagnosis: accept every standard ID and inspect it in
     HAL_FDCAN_RxFifo0Callback(). Restore mask 0x7FF after the test. */
  fdcan_filter.FilterID2 = 0U;

  if (HAL_FDCAN_ConfigFilter(&hfdcan1, &fdcan_filter) != HAL_OK)
  {
    Error_Handler();
  }

  if (HAL_FDCAN_ConfigGlobalFilter(
        &hfdcan1,
        FDCAN_REJECT,
        FDCAN_REJECT,
        FDCAN_REJECT_REMOTE,
        FDCAN_REJECT_REMOTE) != HAL_OK)
  {
    Error_Handler();
  }

  if (HAL_FDCAN_ConfigTxDelayCompensation(&hfdcan1, 32U, 0U) != HAL_OK)
  {
    Error_Handler();
  }

  if (HAL_FDCAN_EnableTxDelayCompensation(&hfdcan1) != HAL_OK)
  {
    Error_Handler();
  }

  if (HAL_FDCAN_Start(&hfdcan1) != HAL_OK)
  {
    Error_Handler();
  }

  if (HAL_FDCAN_ActivateNotification(
        &hfdcan1, FDCAN_IT_RX_FIFO0_NEW_MESSAGE, 0U) != HAL_OK)
  {
    Error_Handler();
  }

  if (DM_Motor_Init(&hfdcan1) != HAL_OK)
  {
    Error_Handler();
  }

  if ((can_test_enabled == 0U) &&
      (HAL_TIM_Base_Start_IT(&htim6) != HAL_OK))
  {
    Error_Handler();
  }

  /* USER CODE END 2 */

  /* Infinite loop */
  /* USER CODE BEGIN WHILE */
  while (1)
  {
    uint8_t index;

    if (can_test_enabled != 0U)
    {
      if ((HAL_GetTick() - can_test_last_tick) >= 100U)
      {
        if (DM_Motor_CanAnalyzerTestSend(can_test_counter) == HAL_OK)
        {
          ++can_test_counter;
          can_test_last_tick = HAL_GetTick();
        }
      }
      HAL_Delay(1U);
      continue;
    }

    if (mit_watch_test_enabled != 0U)
    {
      MIT_WatchTestProcess();
      HAL_Delay(1U);
      continue;
    }

    if (USB_MotorComm_GetCommand(&motor_command) != 0U)
    {
      usb_command_received = 1U;
      last_usb_command_tick = HAL_GetTick();

      requested_control_mode =
        ((motor_command.motor[0].flags &
          USB_MOTOR_FLAG_VELOCITY_MODE) != 0U) ?
        DM_CONTROL_MODE_VELOCITY : DM_CONTROL_MODE_MIT;

      if ((mode_switch_state == MOTOR_MODE_SWITCH_IDLE) &&
          ((control_mode_initialized == 0U) ||
           (requested_control_mode != active_control_mode)))
      {
        Motor_StartControlModeSwitch(requested_control_mode);
      }

      for (index = 0U; index < DM_MOTOR_COUNT; ++index)
      {
        if ((motor_command.motor[index].flags &
             USB_MOTOR_FLAG_CLEAR_ERROR) != 0U)
        {
          motor_action_pending[index] |= MOTOR_ACTION_CLEAR_ERROR;
        }

        if ((motor_command.motor[index].flags &
             USB_MOTOR_FLAG_SET_ZERO) != 0U)
        {
          motor_action_pending[index] |= MOTOR_ACTION_SET_ZERO;
        }

        if ((mode_switch_state == MOTOR_MODE_SWITCH_IDLE) &&
            (control_mode_initialized != 0U) &&
            ((motor_command.motor[index].flags &
              USB_MOTOR_FLAG_ENABLE) != 0U))
        {
          if (motor_enabled[index] == 0U)
          {
            motor_action_pending[index] &=
              (uint8_t)~MOTOR_ACTION_DISABLE;
            motor_action_pending[index] |= MOTOR_ACTION_ENABLE;
          }
        }
        else if ((mode_switch_state == MOTOR_MODE_SWITCH_IDLE) &&
                 (control_mode_initialized != 0U) &&
                 ((motor_enabled[index] != 0U) ||
                  ((motor_action_pending[index] &
                    MOTOR_ACTION_ENABLE) != 0U)))
        {
          motor_enabled[index] = 0U;
          motor_action_pending[index] &= (uint8_t)~MOTOR_ACTION_ENABLE;
          motor_action_pending[index] |= MOTOR_ACTION_DISABLE;
        }
      }
    }

    if ((usb_command_received != 0U) &&
        ((HAL_GetTick() - last_usb_command_tick) > 100U))
    {
      usb_command_received = 0U;
      for (index = 0U; index < DM_MOTOR_COUNT; ++index)
      {
        mode_restore_enabled[index] = 0U;
        if ((motor_enabled[index] != 0U) ||
            ((motor_action_pending[index] & MOTOR_ACTION_ENABLE) != 0U))
        {
          motor_enabled[index] = 0U;
          motor_action_pending[index] &= (uint8_t)~MOTOR_ACTION_ENABLE;
          motor_action_pending[index] |= MOTOR_ACTION_DISABLE;
        }
      }
    }

    Motor_ProcessControlModeSwitch();
    if (mode_switch_state == MOTOR_MODE_SWITCH_IDLE)
    {
      Motor_ProcessPendingAction();
    }

    if (feedback_pending != 0U)
    {
      feedback_pending = 0U;
      if (USB_MotorComm_SendFeedback() != 0U)
      {
        feedback_pending = 1U;
      }
    }
    /* USER CODE END WHILE */

    /* USER CODE BEGIN 3 */
  }
  /* USER CODE END 3 */
}

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
/* USER CODE BEGIN 4 */
void HAL_TIM_PeriodElapsedCallback(TIM_HandleTypeDef *htim)
{
  uint8_t index;

  if (htim->Instance != TIM6)
  {
    return;
  }

  if (mit_watch_test_enabled != 0U)
  {
    ++mit_watch_timer_divider;
    if (mit_watch_timer_divider >= DM_MOTOR_COUNT)
    {
      mit_watch_timer_divider = 0U;
      if (mit_watch_motor_enabled != 0U)
      {
        (void)DM_Motor_MitControl(
          &dm_motors[mit_watch_active_motor_index],
          mit_watch_position,
          mit_watch_velocity,
          mit_watch_kp,
          mit_watch_kd,
          mit_watch_torque);
      }
    }
    return;
  }

  index = motor_control_index;
  if ((usb_command_received != 0U) &&
      (motor_enabled[index] != 0U) &&
      (motor_control_suspended == 0U) &&
      (control_mode_initialized != 0U))
  {
    if (active_control_mode == DM_CONTROL_MODE_VELOCITY)
    {
      (void)DM_Motor_VelocityControl(
        &dm_motors[index],
        motor_command.motor[index].velocity);
    }
    else
    {
      (void)DM_Motor_MitControl(
        &dm_motors[index],
        motor_command.motor[index].position,
        motor_command.motor[index].velocity,
        motor_command.motor[index].kp,
        motor_command.motor[index].kd,
        motor_command.motor[index].torque);
    }
  }

  ++index;
  if (index >= DM_MOTOR_COUNT)
  {
    index = 0U;
    feedback_pending = 1U;
  }
  motor_control_index = index;
}

/* USER CODE END 4 */
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


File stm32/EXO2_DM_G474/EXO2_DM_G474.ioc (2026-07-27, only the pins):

Mcu.UserName=STM32G474VETx
PA11.Signal=USB_DM
PA12.Signal=USB_DP
PA13.Signal=SYS_JTMS-SWDIO
PA14.Signal=SYS_JTCK-SWCLK
PD0.Signal=FDCAN1_RX
PD1.Signal=FDCAN1_TX
PF0-OSC_IN.Signal=RCC_OSC_IN
PF1-OSC_OUT.Signal=RCC_OSC_OUT

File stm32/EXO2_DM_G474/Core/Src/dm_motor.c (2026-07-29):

#include <dm_motor.h>

#include <string.h>

#define DM_MOTOR_MASTER_ID              0x000U

/* These values must match PMAX, VMAX and TMAX inside each motor. */
#define DM_D4340P_POSITION_MAX           12.5f
#define DM_D4340P_VELOCITY_MAX           20.0f
#define DM_D4340P_TORQUE_MAX             28.0f

#define DM_D4310P_POSITION_MAX           12.5f
#define DM_D4310P_VELOCITY_MAX           50.0f
#define DM_D4310P_TORQUE_MAX             10.0f

#define DM_MOTOR_KP_MAX                  500.0f
#define DM_MOTOR_KD_MAX                  5.0f

#define DM_MOTOR_UINT12_MAX              4095U
#define DM_MOTOR_UINT16_MAX              65535U

#define DM_MOTOR_COMMAND_CLEAR_ERROR     0xFBU
#define DM_MOTOR_COMMAND_ENABLE          0xFCU
#define DM_MOTOR_COMMAND_DISABLE         0xFDU
#define DM_MOTOR_COMMAND_SET_ZERO        0xFEU

#define DM_MOTOR_PARAMETER_REQUEST_ID    0x7FFU
#define DM_MOTOR_PARAMETER_WRITE         0x55U
#define DM_MOTOR_CONTROL_MODE_REGISTER   0x0AU
#define DM_MOTOR_CONTROL_MODE_MIT_VALUE  1U
#define DM_MOTOR_CONTROL_MODE_VELOCITY_VALUE  3U

#define DM_MOTOR_VELOCITY_ID_OFFSET      0x200U

#define CAN_TEST_PERIODIC_TX_ID           0x100U
#define CAN_TEST_REQUEST_ID               0x200U
#define CAN_TEST_RESPONSE_ID              0x201U

typedef struct
{
  float position_max;
  float velocity_max;
  float torque_max;
} DM_MotorLimits_t;

DM_Motor_t dm_motors[DM_MOTOR_COUNT] =
{
  {1U, DM_MOTOR_MODEL_D4340P, {DM_MOTOR_STATUS_DISABLED, 0.0f, 0.0f, 0.0f, 0U, 0U}},
  {2U, DM_MOTOR_MODEL_D4340P, {DM_MOTOR_STATUS_DISABLED, 0.0f, 0.0f, 0.0f, 0U, 0U}},
  {3U, DM_MOTOR_MODEL_D4340P, {DM_MOTOR_STATUS_DISABLED, 0.0f, 0.0f, 0.0f, 0U, 0U}},
  {4U, DM_MOTOR_MODEL_D4340P, {DM_MOTOR_STATUS_DISABLED, 0.0f, 0.0f, 0.0f, 0U, 0U}},
  {5U, DM_MOTOR_MODEL_D4310P, {DM_MOTOR_STATUS_DISABLED, 0.0f, 0.0f, 0.0f, 0U, 0U}},
  {6U, DM_MOTOR_MODEL_D4310P, {DM_MOTOR_STATUS_DISABLED, 0.0f, 0.0f, 0.0f, 0U, 0U}},
  {7U, DM_MOTOR_MODEL_D4310P, {DM_MOTOR_STATUS_DISABLED, 0.0f, 0.0f, 0.0f, 0U, 0U}}
};

static FDCAN_HandleTypeDef *s_hfdcan;
static volatile uint8_t s_can_test_enabled = CAN_ANALYZER_LOOPBACK_TEST;

/* Temporary FDCAN RX diagnostics for the debugger Watch window. */
volatile uint32_t dm_can_rx_irq_count;
volatile uint32_t dm_can_rx_frame_count;
volatile uint32_t dm_can_rx_feedback_count;
volatile uint32_t dm_can_rx_rejected_count;
volatile uint32_t dm_can_rx_hal_error_count;
volatile uint32_t dm_can_rx_last_identifier;
volatile uint32_t dm_can_rx_last_data_length;
volatile uint32_t dm_can_rx_last_fd_format;
volatile uint32_t dm_can_rx_last_brs;
volatile uint8_t dm_can_rx_last_data[8];

static const DM_MotorLimits_t s_motor_limits[] =
{
  {DM_D4340P_POSITION_MAX, DM_D4340P_VELOCITY_MAX, DM_D4340P_TORQUE_MAX},
  {DM_D4310P_POSITION_MAX, DM_D4310P_VELOCITY_MAX, DM_D4310P_TORQUE_MAX}
};

static float DM_Motor_Clamp(float value, float minimum, float maximum)
{
  if (value < minimum)
  {
    return minimum;
  }

  if (value > maximum)
  {
    return maximum;
  }

  return value;
}

static uint16_t DM_Motor_FloatToUint(float value,
                                     float minimum,
                                     float maximum,
                                     uint32_t integer_maximum)
{
  value = DM_Motor_Clamp(value, minimum, maximum);
  return (uint16_t)((value - minimum) * (float)integer_maximum /
                    (maximum - minimum));
}

static float DM_Motor_UintToFloat(uint16_t value,
                                  float minimum,
                                  float maximum,
                                  uint32_t integer_maximum)
{
  return ((float)value * (maximum - minimum) / (float)integer_maximum) +
         minimum;
}

static HAL_StatusTypeDef DM_Motor_Send(uint16_t standard_id,
                                       const uint8_t *data,
                                       uint32_t data_length)
{
  FDCAN_TxHeaderTypeDef header;

  if (HAL_FDCAN_GetTxFifoFreeLevel(s_hfdcan) == 0U)
  {
    return HAL_BUSY;
  }

  header.Identifier = standard_id;
  header.IdType = FDCAN_STANDARD_ID;
  header.TxFrameType = FDCAN_DATA_FRAME;
  header.DataLength = data_length;
  header.ErrorStateIndicator = FDCAN_ESI_ACTIVE;
  header.BitRateSwitch = FDCAN_BRS_ON;
  header.FDFormat = FDCAN_FD_CAN;
  header.TxEventFifoControl = FDCAN_NO_TX_EVENTS;
  header.MessageMarker = 0U;

  return HAL_FDCAN_AddMessageToTxFifoQ(s_hfdcan, &header, data);
}

static HAL_StatusTypeDef DM_Motor_SendCommand(const DM_Motor_t *motor,
                                              uint8_t command)
{
  uint8_t data[8] = {0xFFU, 0xFFU, 0xFFU, 0xFFU,
                     0xFFU, 0xFFU, 0xFFU, command};

  return DM_Motor_Send(motor->motor_id, data, FDCAN_DLC_BYTES_8);
}

HAL_StatusTypeDef DM_Motor_Init(FDCAN_HandleTypeDef *hfdcan)
{
  if (hfdcan == NULL)
  {
    return HAL_ERROR;
  }

  s_hfdcan = hfdcan;
  return HAL_OK;
}

HAL_StatusTypeDef DM_Motor_Enable(const DM_Motor_t *motor)
{
  return DM_Motor_SendCommand(motor, DM_MOTOR_COMMAND_ENABLE);
}

HAL_StatusTypeDef DM_Motor_Disable(const DM_Motor_t *motor)
{
  return DM_Motor_SendCommand(motor, DM_MOTOR_COMMAND_DISABLE);
}

HAL_StatusTypeDef DM_Motor_SetZero(const DM_Motor_t *motor)
{
  return DM_Motor_SendCommand(motor, DM_MOTOR_COMMAND_SET_ZERO);
}

HAL_StatusTypeDef DM_Motor_ClearError(const DM_Motor_t *motor)
{
  return DM_Motor_SendCommand(motor, DM_MOTOR_COMMAND_CLEAR_ERROR);
}
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

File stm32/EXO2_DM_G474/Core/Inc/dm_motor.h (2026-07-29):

#ifndef DM_MOTOR_H
#define DM_MOTOR_H

#include <main.h>

#define DM_D4340P_MOTOR_COUNT  4U
#define DM_D4310P_MOTOR_COUNT  3U
#define DM_MOTOR_COUNT          7U

typedef enum
{
  DM_MOTOR_MODEL_D4340P = 0U,
  DM_MOTOR_MODEL_D4310P
} DM_MotorModel_t;

typedef enum
{
  DM_CONTROL_MODE_MIT = 0U,
  DM_CONTROL_MODE_VELOCITY
} DM_ControlMode_t;

typedef enum
{
  DM_MOTOR_STATUS_DISABLED = 0x0U,
  DM_MOTOR_STATUS_ENABLED = 0x1U,
  DM_MOTOR_STATUS_OUTPUT_ENCODER_ERROR = 0x3U,
  DM_MOTOR_STATUS_SENSOR_ERROR = 0x4U,
  DM_MOTOR_STATUS_MOTOR_ENCODER_ERROR = 0x5U,
  DM_MOTOR_STATUS_OVER_VOLTAGE = 0x8U,
  DM_MOTOR_STATUS_UNDER_VOLTAGE = 0x9U,
  DM_MOTOR_STATUS_OVER_CURRENT = 0xAU,
  DM_MOTOR_STATUS_MOS_OVER_TEMPERATURE = 0xBU,
  DM_MOTOR_STATUS_MOTOR_OVER_TEMPERATURE = 0xCU,
  DM_MOTOR_STATUS_COMMUNICATION_LOST = 0xDU,
  DM_MOTOR_STATUS_OVERLOAD = 0xEU
} DM_MotorStatus_t;

typedef struct
{
  DM_MotorStatus_t status;
  float position;
  float velocity;
  float torque;
  uint8_t mos_temperature;
  uint8_t rotor_temperature;
} DM_MotorFeedback_t;

typedef struct
{
  uint8_t motor_id;
  DM_MotorModel_t model;
  volatile DM_MotorFeedback_t feedback;
} DM_Motor_t;

extern DM_Motor_t dm_motors[DM_MOTOR_COUNT];

HAL_StatusTypeDef DM_Motor_Init(FDCAN_HandleTypeDef *hfdcan);
HAL_StatusTypeDef DM_Motor_Enable(const DM_Motor_t *motor);
HAL_StatusTypeDef DM_Motor_Disable(const DM_Motor_t *motor);
HAL_StatusTypeDef DM_Motor_SetZero(const DM_Motor_t *motor);
HAL_StatusTypeDef DM_Motor_ClearError(const DM_Motor_t *motor);
HAL_StatusTypeDef DM_Motor_MitControl(const DM_Motor_t *motor,
                                      float position,
                                      float velocity,
                                      float kp,
                                      float kd,
                                      float torque);
HAL_StatusTypeDef DM_Motor_VelocityControl(const DM_Motor_t *motor,
                                           float velocity);
HAL_StatusTypeDef DM_Motor_SetControlMode(const DM_Motor_t *motor,
                                          DM_ControlMode_t mode);
HAL_StatusTypeDef DM_Motor_CanAnalyzerTestSend(uint32_t counter);

#endif /* DM_MOTOR_H */

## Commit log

2026-07-24 创建独立的Windows STM32分支
2026-07-24 创建独立的Ubuntu ROS分支
2026-07-24 恢复Windows本地仓库目录结构
2026-07-24 branch测试
2026-07-24 第一次正式提交
2026-07-27 EXO2_DM_G474D的stm32代码第一次提交
2026-07-27 ROS2 Jazzy代码第一次提交
2026-07-28 feat(ros1): support seven-motor STM32G474 protocol
2026-07-28 stm32和dm电机通讯测试通过
2026-07-28 修复usb通讯时收不到 feedback的错误
2026-07-29 添加速度控制模式
2026-08-05 Update ROS Jazzy packages
    [estimator_kinematics.urdf, excitation_id.csv, excitation_validation.csv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]
2026-08-26 exo_urdf模型上传
    [base_link.STL, link1.STL, link2.STL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]
2026-08-27 feat(ros2): synchronize Jazzy workspace
    [prediction_id.csv, prediction_validation.csv, training_history.csv]
2026-09-30 feat: add collision-safe MuJoCo workflow
    [base_link_1_collision_hull.stl, compensation_validation_sim.csv, dynamics_id_sim.csv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]

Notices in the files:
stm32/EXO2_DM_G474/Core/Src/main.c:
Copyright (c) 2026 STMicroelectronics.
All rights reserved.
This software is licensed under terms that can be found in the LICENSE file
